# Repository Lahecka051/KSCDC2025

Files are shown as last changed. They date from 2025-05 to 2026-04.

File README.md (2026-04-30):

# KSCDC2025 — Team Prometheus

<p align="center">
  
  
  
  
  
  
  
</p>

> **스마트 드론을 활용한 실시간 화재 탐지 및 초기 소화 시스템**
>
> NVIDIA Jetson Orin Nano Super 기반, 딥러닝 객체인식을 통한 자율 순찰 및 소화볼 투하가 가능한 화재 대응 드론 시스템

---

## 목차

1. [프로젝트 개요](#프로젝트-개요)
2. [팀원](#팀원)
3. [시스템 아키텍처](#시스템-아키텍처)
4. [운용 시나리오](#운용-시나리오)
5. [폴더 구조](#폴더-구조)
6. [소프트웨어 모듈 상세](#소프트웨어-모듈-상세)
7. [하드웨어 사양](#하드웨어-사양)
8. [소프트웨어 스택](#소프트웨어-스택)
9. [통신 프로토콜](#통신-프로토콜)
10. [대회 일정](#대회-일정)
11. [라이선스](#라이선스)

---

## 프로젝트 개요

| 항목 | 내용 |
|---|---|
| 대회 | 2025 KSCDC (한국기계학회 창의설계경진대회) |
| 소속 | 경성대학교 |
| 기간 | 2025.05.02 ~ 2025.09.12 |
| 대회 홈페이지 | http://kscdc.ksme.or.kr/ |

## 팀원

| 이름 | 역할 |
|---|---|
| 이강민 | 조장 |
| 권혁준 | 팀원 |
| 송승진 | 팀원 |
| 유찬영 | 팀원 |
| 김철우 | 팀원 |

## 시스템 아키텍처

```
┌─────────────────┐       TCP/IP        ┌──────────────────┐       TCP/IP       ┌─────────────────┐
│   PC 관제 센터   │ ◄──────────────────► │   드론 (Jetson)   │                   │  Station (RPi)  │
│   (pc_server)   │    명령/보고 전송     │   (main.py)      │                   │  (station.py)   │
│                 │                      │                  │                   │                 │
│  - 지도 GUI     │  ← 화재 보고/이미지   │  - 화재 탐지      │                   │  - 소화볼 장전   │
│  - 경로 설정    │  → 순찰/진압 명령     │  - 자율 순찰      │                   │  - 도킹 정렬    │
│  - 진압 승인    │                      │  - 소화볼 투하    │                   │  - ToF 센서     │
│  - 사진 수신    │                      │  - 자동 착륙      │                   │                 │
└─────────────────┘                      └──────────────────┘                   └─────────────────┘
       :65524 (수신)                        :65523 (수신)                           :65525 (수신)
```

## 운용 시나리오

1. **순찰 명령** — PC 관제 센터에서 지도 위 경로점(Waypoint) 설정 후 드론에 전송
2. **자율 순찰** — 드론이 경로점을 따라 비행하며 정면 카메라(IMX477)로 YOLOv8s 화재/연기 탐지
3. **화재 확인** — 5초간 30프레임 이상 연속 감지 시 화재 확정, GPS 좌표 추정 후 화재 지점 이동
4. **하단 정렬** — 하단 카메라(IMX219)로 화재 위치에 드론 정밀 정렬
5. **화재 보고** — 현장 사진 촬영 후 PC 관제 센터로 좌표 및 이미지 전송
6. **홈 복귀 및 착륙** — 홈 좌표로 복귀 후, 빨간 마커 추적 기반 정밀 착륙
7. **진압 승인** — 관제 센터에서 화재 보고 확인 후 진압 승인 버튼 클릭
8. **소화볼 장전** — Station(Raspberry Pi)에 소화볼 장전 명령 전송
9. **소화볼 투하** — 드론이 화재 지점으로 재출격, 정렬 후 서보 모터로 소화볼 투하
10. **임무 완료** — 홈 복귀 및 착륙, 완료 상태 보고

## 폴더 구조

```
KSCDC2025/
├── README.md                          # 프로젝트 개요 (본 문서)
├── LICENSE                            # MIT License
├── .gitignore                         # Python/모델/로그 제외
├── .gitattributes                     # 줄바꿈 정규화 (LF)
│
├── Datasheets/                        # 부품 데이터시트 및 사양
│   ├── Filament.md                    #   3D 프린트 필라멘트
│   ├── Frame.md                       #   X6-X600 드론 프레임 (600mm)
│   ├── IMX219 Camera Module.md        #   하단 카메라 (160도 광각)
│   ├── IMX477 Camera Module.md        #   정면 카메라 (63도)
│   ├── JetsonOrinNanoSuper.md         #   NVIDIA Jetson Orin Nano Super
│   ├── MicoAir H743v2.md              #   FC (비행 컨트롤러)
│   ├── Motor & Propeller.md           #   Airgear 350 모터 & 프로펠러
│   └── Servo.md                       #   소화볼 투하용 서보 모터
│
├── Regular_Meeting/                   # 정기 회의록 (2025.05 ~ 2025.09)
│
├── Report/                            # 공식 보고서 (PDF)
│   ├── 설계제안서_프로메테우스_이강민.pdf
│   ├── 중간보고서_프로메테우스_이강민.pdf
│   └── 최종보고서_프로메테우스_이강민.pdf
│
├── STL/                               # 3D 프린트 모델 파일
│   ├── Drone/                         #   드론 탑재 부품 (소화볼 하우징/플레이트)
│   │   ├── Drone_4inch_Ball.stl
│   │   ├── Drone_BAT_House_Hook.stl
│   │   ├── Drone_BAT_House_Lower.stl
│   │   ├── Drone_BAT_House_Upper.stl
│   │   └── Drone_Bomb_Plate.stl
│   └── Station/                       #   스테이션 메커니즘 (랙앤피니언)
│       ├── Station_Bar.stl
│       ├── Station_Pinion.stl
│       └── Station_Rack.stl
│
└── Software/
    ├── Drone/                         # 드론 탑재 소프트웨어 (Jetson Orin Nano)
    │   ├── main.py                    #   메인 엔트리포인트 — 명령 수신 및 미션 분배
    │   ├── drone_controller.py        #   MAVLink FC 제어 (ARM, 이륙, GPS 이동, 착륙)
    │   ├── Fire_detector.py           #   YOLOv8s TensorRT 화재/연기 탐지 및 GPS 추정
    │   ├── Fire_extinguishing.py      #   소화볼 투하 미션 시퀀스
    │   ├── patrol.py                  #   자율 순찰 (경로점 이동 + 실시간 화재 감시)
    │   ├── Landing.py                 #   빨간 마커 추적 기반 정밀 착륙
    │   ├── DroneCommunicator.py       #   PC 관제 센터 TCP 통신 (보고/명령)
    │   ├── servo_control.py           #   소화볼 투하 서보 PWM 제어
    │   └── pipeline.py                #   GStreamer CSI 카메라 파이프라인
    │
    ├── PC/                            # PC 관제 센터 소프트웨어
    │   ├── pc_server.py               #   Tkinter 관제 GUI (지도, 경로, 화재 대응)
    │   ├── pc_rpi_server.py           #   Station(RPi) TCP 통신 서버
    │   └── pc_server.exe              #   빌드된 실행 파일
    │
    └── Station_WIP/                   # 드론 스테이션 [개발 중단 / Work In Progress]
        ├── station.py                 #   스테이션 메인 — 서보, ToF 센서, 도킹 제어
        ├── Doc_match.py               #   카메라 기반 도킹 마커 감지
        └── rpi_client.py              #   PC 서버 TCP 통신 클라이언트
```

## 소프트웨어 모듈 상세

### Drone (Jetson Orin Nano)

| 모듈 | 설명 |
|---|---|
| `main.py` | 시스템 진입점. PC로부터 TCP 명령을 수신하여 순찰(list) 또는 진압(EXTINGUISH) 미션을 스레드로 분배 |
| `drone_controller.py` | pymavlink 기반 FC 제어. GUIDED/RTL/LAND/BRAKE 모드 전환, ARM/DISARM, GPS 이동(goto_gps), 하버사인 거리 계산 |
| `Fire_detector.py` | YOLOv8s TensorRT 엔진으로 정면 카메라 화재/연기 탐지. 5초 30프레임 확정 로직, 카메라 각도 기반 화재 GPS 추정, 하단 카메라 객체 정렬 |
| `patrol.py` | 경로점 순회 + 실시간 화재 감시 스레드 병행. 화재 확정 시 화재 지점 이동 → 정렬 → 사진 촬영 → 홈 복귀 → 보고 전송 |
| `Fire_extinguishing.py` | 화재 지점 GPS 이동 → 하단 카메라 정렬 → 서보 180도 회전으로 소화볼 투하 → 홈 복귀 → 완료 보고 |
| `Landing.py` | 하단 카메라 빨간 마커(Red Dot) HSV 감지. 비례 제어로 마커 중앙 정렬하며 하강, 10초 미감지 시 LAND 모드 전환 |
| `DroneCommunicator.py` | PC 관제 센터로 화재 보고(좌표+이미지) 및 상태 업데이트 TCP 전송. 포트 65523에서 명령 수신 서버 운영 |
| `servo_control.py` | Jetson GPIO PWM 서보 제어. 0도=재장전(idle), 180도=투하 |
| `pipeline.py` | IMX477(30fps 1920x1080) / IMX219(21fps 1640x1232) 센서별 GStreamer 파이프라인 생성 |

### PC 관제 센터

| 모듈 | 설명 |
|---|---|
| `pc_server.py` | Tkinter + TkinterMapView 지도 GUI. 우클릭 경로점 추가, 순찰 명령 전송, 화재 보고 수신 시 지도 핑 + 사진 표시 + 진압 승인 |
| `pc_rpi_server.py` | Station(RPi)과의 TCP 서버. 소화볼 장전 명령 전송 및 응답 수신. 포트 65525 |

### Station [WIP — 개발 중단]

| 모듈 | 설명 |
|---|---|
| `station.py` | 서보 3축(전후/좌우/장전) + ToF 센서 4개(VL53L0X)로 드론 도킹 및 소화볼 장전 자동화 |
| `Doc_match.py` | CSI 카메라 빨간 마커 감지 (원형도/종횡비 필터링) 기반 도킹 정렬 |
| `rpi_client.py` | PC 서버 TCP 클라이언트. 명령 수신 큐 + JSON 응답 전송, 자동 재연결 |

## 하드웨어 사양

| 구성 요소 | 사양 |
|---|---|
| **개발보드** | NVIDIA Jetson Orin

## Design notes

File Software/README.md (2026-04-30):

# Software

KSCDC2025 프로메테우스 시스템 소프트웨어 구성. 3개 노드(PC 관제 / 드론 / 스테이션)로 구성된 분산 시스템.

```
PC 관제 (Tkinter GUI)  ───TCP───  Drone (Jetson Orin Nano)
        │
        └────TCP────  Station (Raspberry Pi, WIP)
```

## Drone/ — 드론 탑재 (Jetson Orin Nano Super)

YOLOv8s + TensorRT 기반 화재/연기 실시간 탐지 및 자율 비행/투하.

### 실행

```bash
cd Software/Drone
python3 main.py
```

### 의존성

- Python 3.10
- pymavlink, OpenCV (CUDA), TensorRT, ultralytics
- Jetson.GPIO
- GStreamer + nvarguscamerasrc (CSI 카메라)

### 진입점

`main.py` — PC 관제로부터 TCP 명령 수신 후 미션 분배 (순찰/진압).

## PC/ — 관제 센터 (Windows/Linux)

Tkinter + TkinterMapView 지도 GUI. 경로점 설정, 화재 보고 수신, 진압 승인.

### 실행

```bash
cd Software/PC
python pc_server.py
```

또는 빌드된 `pc_server.exe` 실행 (Windows).

### 의존성

- Python 3.10
- tkinter, tkintermapview, Pillow

## Station_WIP/ — 자동 장전 스테이션 [개발 중단]

Raspberry Pi 기반 자동 도킹/장전 시스템. 시간 부족으로 본 대회에서는 미투입, 향후 확장 작업용.

### 구성

- 서보 3축(전후 / 좌우 / 장전 회전)
- ToF 센서 4개 (VL53L0X) — 도킹 거리 측정
- CSI 카메라 — 빨간 마커 도킹 정렬

## 통신 포트

| 노드 | 수신 포트 | 용도 |
|---|---|---|
| 드론 | 65523 | PC → 드론 명령 |
| PC | 65524 | 드론 → PC 보고 |
| Station | 65525 | PC → Station 장전 명령 |

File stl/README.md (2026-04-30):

# STL — 3D Print Models

KSCDC2025 프로젝트에서 자체 설계 후 3D 프린팅한 부품 모델 모음.

## Drone/

드론 본체에 장착되는 부품. 소화볼(4인치)을 거치/투하하기 위한 BAT(Bomb Attachment) 하우징과 플레이트.

| 파일 | 용도 |
|---|---|
| `Drone_4inch_Ball.stl` | 4인치 소화볼 검증용 더미 모델 |
| `Drone_BAT_House_Upper.stl` | 소화볼 하우징 상부 |
| `Drone_BAT_House_Lower.stl` | 소화볼 하우징 하부 |
| `Drone_BAT_House_Hook.stl` | 소화볼 고정 후크 (서보 회전으로 해제) |
| `Drone_Bomb_Plate.stl` | 드론 하단 BAT 마운트 플레이트 |

## Station/

스테이션(자동 장전기)의 랙앤피니언 메커니즘 부품. 개발 중단(WIP) 상태.

| 파일 | 용도 |
|---|---|
| `Station_Rack.stl` | 직선 이송용 랙 기어 |
| `Station_Pinion.stl` | 서보 결합 피니언 기어 |
| `Station_Bar.stl` | 가이드 바 |

## 출력 권장 사양

| 항목 | 값 |
|---|-----|
| 필라멘트 | PLA (자세한 사양은 [Datasheets/Filament.md](../Datasheets/Filament.md)) |
| 레이어 두께 | 0.2 mm |
| 인필 | 30 ~ 50% (하중 부품은 50%) |
| 서포트 | 부품별 필요 시 |

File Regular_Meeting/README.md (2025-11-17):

# == 정기 회의록 ==
- KSCDC2025 팀 프로젝트 회의 진행중 나온 의견을 정리하는 장소입니다.
- 메인 페이지의 정리된 회의 내용은 회의 종료 후 2일 이내 업데이트 됩니다.
- 자세한 사항은 당일 회의록을 참고하시기 바랍니다.

# Paste_Data : 09.11(목) (latest update) 

### 정기 회의일
- 매주 (수,목)요일 14:00 ~ 20:00

## 논의 내용
- 하드웨어 & 소프트웨어 제작

## 진행 상황
### 소프트웨어
- 젯슨 CSI 카메라 객체인식 테스트 YOLOv8s
- FC의 데이터를 텔레메트리를 이용하여 실시간 모니터링 가능한 지상국 구축
- FC의 모터 PWM 신호 애널라이징 후 신호 복제하여 무선 모터 조종 테스트

### 기계공학적인 차별점이 필요
- 드론 하단부 소화탄 발사기 ( 소화탄 다연장 회전식 매커니즘 ) 탈부착
- 탈착일때 정찰용, 부착일때 화재진압용
- 드론스테이션 자동화 플랫폼

## 확정된 부품
- 예산 : 30만원 + @

#### 모터 : 이동희 교수님 
- Airgear 350 Combo Set Multi-Rotor UAV Power 4pcs Set X2
- 9.5 X 4.5 two blade Propeller
  
#### FC(Flight Controller)
- 미코에어 H743 V2 신형 픽스호크 비행 컨트롤러 (ARDUPILOT ONLY)
- [FC 구매 링크](https://ko.aliexpress.com/item/1005008824819033.html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)

#### 카메라
- 정면 : IMX477 6mm 63 degree
- 바닥 : IMX219 160 degree

#### 배터리 
- LiPo 4S(14.8V) 8,400mAh 130C X2 
- IMAX B6 LiPo 충전기
- [배터리 구매 링크](https://ko.aliexpress.com/item/1005001956377380.html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)
- [충전기 구매 링크](https://ko.aliexpress.com/item/1005005231331856.html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)

#### 개발보드 
- Jetson Orin Nano Super
- [개발보드 공식 링크](https://www.nvidia.com/ko-kr/autonomous-machines/embedded-systems/jetson-orin/nano-super-developer-kit/)

### 소프트웨어
- UBUNTU_GUI 22.04 LTS (Jetpack6.2.1)
- Ardupilot 5.4.2
- USED OPENCV CUDA TensorRT
- YOLO MODEL : YOLOv8s

## 프레임
- 페이로드 : 3kg 이하, 사이즈 : 300x300 mm 이상
- X6-X600 FPV 프레임 600mm / 30A ~ 40A / 2212 920KV 모터
- [프레임 구매 링크](https://ko.aliexpress.com/item/1005008274592701.html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)

### 부품 공식 제원 상 무게
- jetson orin nano super : Dimensions = 100mm x 79mm x 21mm, Weight = 176g, Power = 5V_Input(5W ~ 25W)
- Camera : 수정
- Flight Controller Spec : Mounting = 30.5mm x 30.5mm x 4mm, Dimensions = 36mm x 36mm x 8mm, Weight = 10g
- 14.8V 8400mah 130C 리포 하드케이스 크기: 138 x 47 x 49mm 무게 639g.
- 소화볼 규격: 지름 4inch(약 100mm), 약 400g
- [소화볼 규격 링크](https://fireds.com/product/%EC%BD%94%EB%81%BC%EB%A6%AC%EC%86%8C%EB%B0%A9%EB%A7%88%ED%8A%B8-%ED%99%94%EC%9D%B4%EC%96%B4%EB%B3%BC4%EC%9D%B8%EC%B9%98-%ED%99%94%EC%9E%AC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)
## 앞으로 진행할 내용
- 젯슨 객체인식 소프트웨어 & 지상국 소프트웨어 구체화

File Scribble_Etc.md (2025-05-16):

## Jetson Orin Nano Super (66만원) 
- AI Performance	67 INT8 TOPS
- GPU	NVIDIA Ampere architecture with 1024 CUDA cores and 32 tensor cores
- CPU	6-core Arm® Cortex®-A78AE v8.2 64-bit CPU 1.5MB L2 + 4MB L3
- Memory 8GB 128-bit LPDDR5 102 GB/s
- Storage	Supports SD card slot and external NVMe
- Power	7W – 25W

### YOLO v8 Processing data = Y1

▲

## [ UART Protocol Communication ]
- ### 통신에 영향을 주는 요소
- 클럭에 따른 BaudRate 에러율 ( 목표 : 0% ) 
- Serial Communication Module Maximum data Throughput
- 통신에 영향을 주는 BaudRate에 따른 Cable Length ( Option : 차폐 기능 )
- 해상도에 따른 처리 시간 변화 ( BaudRate와 Cable Length에 영향을 받음 )

▼

## FC ( Flight Controller )

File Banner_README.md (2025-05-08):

# KSCDC2025 [Team Prometheus]
KSCDC2025 Kyungsung Univ Project

# 2025.05.02 ~ 2025.09.12
- 설계제안서 접수: 2025년 4월 7일(월) ~ 5월 2일(금) 온라인 접수
- 중간보고서 접수: 2025년 6월 2일(월) ~ 6월 27일(금) 온라인 접수
- 본선 진출 팀 선정결과: 2025년 7월 14일(월) email 통보
- 최종보고서 접수: 2025년 8월 25일(월) ~ 9월 12일(금) 온라인 접수
- 최종 본선 진출 팀 선정결과: 2025년 9월 29일(월) email 통보
- 최종 본선 진출 팀 구두발표, 심사 및 시상 : 2025년 10월 25일(토)

# 스마트 드론을 활용한 실시간 화재 탐지 및 초기 소화 시스템
Nvidia Jetson Development Board 기반 소화탄 투척이 가능한 딥러닝 자율주행 드론

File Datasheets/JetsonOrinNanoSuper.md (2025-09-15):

# Jetson Orin Nano Super Specifications



# GPIO PINS MAP (33_PWM Activated)



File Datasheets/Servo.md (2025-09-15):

# Datasheet 
Used Servo : [SG90](http://www.ee.ic.ac.uk/pcheung/teaching/DE1_EE/stores/sg90_datasheet.pdf)



# Trigger Image


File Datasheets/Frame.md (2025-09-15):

# X600 Quardcopter Frame Specifications
[구매링크](https://speedyfpv.com/products/600mm-carbon-fiber-hexacopter-drone-frame-kit-new)

Frame Head Diameter ----> 



# 3K Carbon Fiber Properties
PDF Link ----> [3K Carbonfiber](https://www.toraycma.com/wp-content/uploads/T300-Technical-Data-Sheet-1.pdf)



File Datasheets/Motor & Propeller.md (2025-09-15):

# T-Moter 2213/920KV 모터 세트
[구매링크](https://store.tmotor.com/product/air-gear-350-combo-set.html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)

# Motor Diameter


# Power Efficiency


# Propeller Specifications


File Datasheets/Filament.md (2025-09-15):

# 필라멘트 (PLA, ABS)

### 드론 상단부 (열영향 비교적 적게 받는 부분 설계에 사용)

구매링크 : [PLA](https://smartstore.naver.com/3d-rainbow/products/8816025124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)

===================================================================================

### 드론 하단부 (열영향 비교적 많이 받는 부분 설계에 사용)

구매링크 : [ABS](https://smartstore.naver.com/sondori/products/9590869360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)

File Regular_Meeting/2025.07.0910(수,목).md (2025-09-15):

# 7주차 회의내용

## 논의 내용
- 하드웨어 & 소프트웨어 제작

## 진행 상황
### 소프트웨어
- YOLOv8s의 화재 탐지모델 데이터셋 구글 코랩을 이용하여 학습
- FC의 데이터를 텔레메트리를 이용하여 실시간 모니터링 가능한 환경 구축
- FC의 accypr & gps data를 이용한 드론 방향제어 로직 생성

### 부품 공식 제원 상 무게
jetson orin nano super : Dimensions = 100mm x 79mm x 21mm, Weight = 176g, Power = 5V_Input(5W ~ 25W)
Camera : 3g x 2 = 6g
Flight Controller Spec : Mounting = 30.5mm x 30.5mm x 4mm, Dimensions = 36mm x 36mm x 8mm, Weight = 10g

# 0710 할 일
1. 필라멘트 도착하면 그리퍼 출력 -> 소화볼 출력
2. 역설계 모델링
3. 피드백 고려

# 1. 소화볼 규격
4인치 / 약 10cm // 6인치 고려 / 약 15cm

[소화볼 판매 사이트](https://fireds.com/product/%EC%BD%94%EB%81%BC%EB%A6%AC%EC%86%8C%EB%B0%A9%EB%A7%88%ED%8A%B8-%ED%99%94%EC%9D%B4%EC%96%B4%EB%B3%BC4%EC%9D%B8%EC%B9%98-%ED%99%94%EC%9E%AC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)

# 2. 필라멘트 (PLA, ABS)
[PLA](https://smartstore.naver.com/3d-rainbow/products/8816025124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)

[ABS](https://smartstore.naver.com/sondori/products/9590869360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)

# 3. 기판 / 배터리 / Jetson / 배치 고려
-> 아래쪽 V자 평판 구조 새로 제작



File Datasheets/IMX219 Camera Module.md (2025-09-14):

# IMX219 160도 광각 카메라 모듈 8MP

## 사양
- 인터페이스 : CSI
- 해상도 : 3280 × 2464
- 크기 : 25mm × 24mm
- 케이블 길이 : 약 16cm
- 4개의 나사 구멍으로 3.3V의 직류 공급이 가능합니다.

## 렌즈 사양
- CMOS 크기 : 1/4인치
- 조리개 : F2.35
- 초점 거리 : 3.15mm
- 화각 : 160°
- 왜곡 : <14.3%

## 구성품
- 카메라모듈 1개
- 15핀 FFC 케이블 1개
 
## 카메라 테스트 명령어
DISPLAY=:0.0 gst-launch-1.0 nvarguscamerasrc ! 'video/x-raw(memory:NVMM), width=3280, height=2464, format=(string)NV12, framerate=(fraction)20/1' ! nvoverlaysink -e

## 화상이 빨갛게(자주빛으로) 보일 때
- wget https://www.waveshare.com/w/upload/e/eb/Camera_overrides.tar.gz
- tar zxvf Camera_overrides.tar.gz
- sudo cp camera_overrides.isp /var/nvidia/nvcam/settings/
- sudo chmod 664 /var/nvidia/nvcam/settings/camera_overrides.isp
- sudo chown root:root /var/nvidia/nvcam/settings/camera_overrides.isp

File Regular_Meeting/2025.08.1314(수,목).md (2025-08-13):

# 진행상황
## 소프트웨어

착륙 객체인식 CSI 카메라 1개 정확도
FHD 기준 지름 5CM 착륙 H 마커 인식거리 1.5M

화재 객체인식 CSI 카메라 2개 작동 성공 & 객체인식 정확도 상세 제원 필요
70~80cm 거리 지름 5CM 화재이미지 인식

드론 UART MAVLink2 연결 성공
Jetson PIN6(GND)==FC(UART4(black)), PIN8(TX)==FC(UART4(green)), PIN10(RX)==FC(UART4(yellow)) 연결
드론 데이터 통신 & 방향제어 로직 제작중

관제센터 GUI 제작중

## 하드웨어
  
배터리 하우징 완성
FC& 전력분배PCB 하우징 완성
카메라 하우징 완성
젯슨 하우징 환성
소화탄 투하기 제작중

# 앞으로 할일

## 소프트웨어

드론스테이션 통신 구상하기

## 하드웨어
소화탄 투하기 만들기
드론스테이션 구상하기

### 마감 08월 29일 까지

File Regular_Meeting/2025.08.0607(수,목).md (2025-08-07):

# 진행상황
## 소프트웨어

착륙 객체인식 CSI 카메라 1개 정확도
FHD 기준 지름 5CM 착륙 H 마커 인식거리 1.5M

화재 객체인식 CSI 카메라 2개 작동 성공 & 객체인식 정확도 상세 제원 필요

드론 UART MAVLink2 연결 성공
Jetson PIN6(GND)==FC(UART4(black)), PIN8(TX)==FC(UART4(green)), PIN10(RX)==FC(UART4(yellow)) 연결

## 하드웨어
  
배터리 하우징 완성
FC& 전력분배PCB 하우징 완성
카메라 하우징 제작중

# 앞으로 할일

## 소프트웨어

드론스테이션 통신 구상하기
관제센터 GUI 만들기

## 하드웨어

Jetson 적층 하우징 만들기
소화탄 투하기 만들기
드론스테이션 구상하기

### 마감 08월 29일 까지

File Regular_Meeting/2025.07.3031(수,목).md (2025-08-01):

하드웨어팀 소화볼 투하기 & 배터리 하우징 모델링 & 젯슨, FC 고정 하우징 제작

소프트웨어팀 FC 젯슨 UART 의존성 업데이트 & 지상국에서 모터 제어 PWM 신호 측정 및 싱크로나이즈 작업 1명, 젯슨 OPENCV CUDA 관련 의존성 업데이트 및 CSI 카메라 객체인식 테스트 2명

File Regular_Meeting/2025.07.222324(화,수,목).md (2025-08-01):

하드웨어팀 소화볼 투하기 & 배터리 하우징 모델링

소프트웨어팀 FC 젯슨 UART 의존성 업데이트 & 지상국에서 모터 제어 PWM 신호 측정 및 싱크로나이즈 작업 1명, 젯슨 OPENCV CUDA 관련 의존성 업데이트 및 CSI 카메라 테스트 2명

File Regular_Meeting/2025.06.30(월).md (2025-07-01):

# 6주차 회의내용

## 논의 내용
- 하드웨어 제작 정기 회의 날짜 지정
- 하드웨어 & 소프트웨어 각자 맡은 작업 구체화

## 확정된 부품

#### 모터 : 이동희 교수님 
- Airgear 350 Combo Set Multi-Rotor UAV Power 4pcs Set X2
- 9.5 X 4.5 two blade Propeller
  
#### FC(Flight Controller)
-미코에어 H743 V2 신형 픽스호크 비행 컨트롤러

#### 카메라
- 정면 : IMX219 160 degree
- 바닥 : IMX219 120 degree

### 배터리 
- LiPo 4S(14.8V) 8,400mAh 130C X2 
- IMAX B6 LiPo 충전기

### 개발보드 :  Jetson Orin Nano Super

### 소프트웨어
- Linux_Based (Ardupilot, YOLOv8s, UBUNTU_GUI 24.2)

## 프레임
- X6-X600 FPV 프레임 600mm / 30A ~ 40A / 2212 920KV

### 부품 공식 제원 상 무게
jetson orin nano super : Dimensions = 100mm x 79mm x 21mm, Weight = 176g, Power = 5V_Input(5W ~ 25W)
Camera : 3g x 2 = 6g
Flight Controller Spec : Mounting = 30.5mm x 30.5mm x 4mm, Dimensions = 36mm x 36mm x 8mm, Weight = 10g

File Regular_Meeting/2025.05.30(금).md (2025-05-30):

# 4주차 회의내용

## 논의 내용
- 모터 추가에 대한 쿼드콥터에서 헥사콥터로 형태 변경
- 부품 결정 및 구매
- 대한기계학회에서 제시한 보완 사항 논의

## 확정된 부품

### 모터 : 이동희 교수님 
- Airgear 350 Combo Set Multi-Rotor UAV Power 4pcs Set X2

### FC(Flight Controller)
-미코에어 H743 V2 신형 픽스호크 비행 컨트롤러

### 카메라
- 정면 : IMX219 160 degree
- 바닥 : IMX219 120 degree

## 배터리 : 4S(14.8V) 
- 5,000mAh ~ 10,000mAh

### 개발보드 :  Jetson Orin Nano Super

### 소프트웨어
- Linux_Based (Ardupilot, YOLOv8s, UBUNTU_GUI 24.2)

## 프레임
- 우선사항 [ 프레임 무게, 페이로드 : 3kg 까지 ]
- 페이로드 : 3kg 이하, 사이즈 : 300x300 mm 이상

## 추가할 사항
- 기성품 소화탄 규격에 맞춰 설계할 필요있음

## 확정된 사항
-

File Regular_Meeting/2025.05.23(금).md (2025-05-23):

# 3주차 회의내용

## 논의 내용
- 부품 구매리스트 확정 및 중가보고서에 작성할 개념 설계적인 부분 보완

### 기계공학적인 차별점이 필요
- 드론 하단부 소화탄 발사기 ( 소화탄 다연장 회전식 매커니즘 ) 탈부착 가능하게
- 탈착일때 정찰용, 부착일때 화재진압용
- 드론스테이션 자동화 플랫폼 ( 고려 )

## 확정된 부품

### 모터 : 이동희 교수님 공짜
- Airgear 350 Combo Set Multi-Rotor UAV Power

### FC(Flight Controller) 100,000원
-미코에어 H743 V2 신형 픽스호크 비행 컨트롤러

### 카메라
- 정면 : IMX219 160 degree 18,000원
- 바닥 : IMX219 120 degree 15,000원
- Total : 35,000원
  
## 미확정 부품

## 배터리 : 4S(14.8V) 
- 5,000mAh ~ 10,000mAh 70,000원

### 개발보드 : 박장식 교수님 (Jetson Board)
- 개발보드 : 박장식 교수님한테 대여

### 소프트웨어
- Linux_Based (Ardupilot, YOLO(Version not yet), UBUNTU 18 OR 20

## 프레임
- 우선사항 [ 프레임 무게, 페이로드 : 3kg 까지 ]
- 페이로드 : 2kg 이하, 사이즈 : 300x300 mm 이상

## 추가할 사항
- 기성품 소화탄 규격에 맞춰 설계할 필요있음
- 각 부품별로 무게 취합 (최대 2kg)

## 확정된 사항
- 
## 앞으로 진행 계획

**팀원 김형찬 미참**

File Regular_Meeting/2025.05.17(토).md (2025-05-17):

# 2주차 회의내용 (수요일과 동일)

## 논의 내용
- 예산 확정에 따른 구체적인 계획수립 및 중간보고서 작성 방향성 제시

### 기계공학적인 차별점이 필요
- 드론 하단부 소환탄 발사기 ( 소화탄 다연장 회전식 매커니즘 ) 탈부착 가능하게
- 탈착일때 정찰용, 부착일때 화재진압용
- 드론스테이션 자동화 플랫폼 ( 고려 )

## 필요한 부품 선정 ( 1~3개 )
### 프레임(쿼드콥터)
- 우선순위 : 크기, 하중무게 , 비용
- 크기 : 최소 300mm X 300mm (min)
- 하중무게 : 2kg ~ 5kg (min ~ max)
- 예산 : 최대 5만원

### 모터 : 이동희 교수님 (Unknown) 
- 우선순위 : 토크, RPM, 무게, 비용
- 토크 :
- RPM :
- 무게 :
- 예산 : 최대 20만원

### 개발보드 : 박장식 교수님 (Jetson Board)
- 개발보드 : 박장식 교수님한테 대여
- 정확한 기종은 확정 안됨 & 보드 호환 카메라 모듈 유무 확인 후 대여 가능한지 물어보기
  
### 소프트웨어
- Linux_Based (Ardupilot, YOLO(Version not yet)

### FC(flight controller) 
- 예산 : 최대 15만원

### FC_List
- 마텍 f722-se 드론 컨트롤러
- 픽스호크 시리즈 별로 알아보기
  
## 추가할 사항
### 3주차 금요일 까지 과제
- 구글독 스페이스에 각자 담당한 부품 선정 리스트 만들어 오기

## 확정된 사항
- 지원 예산 : 30만원 (일시지급, 사용 후 정산) / 필수기재 사항 : [ 제품명 & 금액 ]
- 추가 예산 : 고려중 (인당 n만원)
- 
## 앞으로 진행 계획
- 3주차 : 부품 구매 확정된 내용 바탕으로 중간보고서 작성에 필요한 이론적인 내용 및 실제 작성

**팀원 김형찬 미참**

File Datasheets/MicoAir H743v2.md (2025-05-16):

# MicoAir743 V2 비행 컨트롤러
- Ardupilot/PX4/INAV/Betaflight 를 지원하는 듀얼 IMU 및 나침반 센서가 내장된 고성능 H743 비행 컨트롤러 입니다. 
- 펌웨어/ 핀아웃 링크: https://micoair.com/flightcontroller_micoair743v2/
- 매뉴얼: https://micoair.com/docs/micoair743-user- manual/
- 기본적으로 Ardupilot 이 설치되어 있습니다. 
- *PX4 설치시 stm32cube Programmer 를 이용하여 bootloader (bin 또는 ef) 파일을 먼저 설치하시고, QGC 에서 px4 펌웨어를 설치하시면 됩니다. 
- *펌웨어 설치 방법 참고 : https://youtu.be/H7TsouQIBfg 
- ESC 가 8비트 Bluejay 에서 32비트 AM32 로 업그레이드 되었습니다.
- 납땜 전에 반드시 USB 를 먼저 꽂아서 정상 작동하는지 점검하십시오. 납땜 이후에는 어떤 경우에도 초기 불량 처리가 되지 않습니다.

## Ardupilot 셋팅시 참고 파라미터 > 
- SERVO1_FUNCTION : 34 (M2) 
- SERVO2_FUNCTION : 35 (M3) 
- SERVO3_FUNCTION : 36 (M4) 
- SERVO4_FUNCTION : 33 (M1) 
- MOT PWM -TYPE : 6( (Dshot 600)
- SERVO _DSHOT ESC : 3 (AM32) 
- SERVO_BLH_BDMASK : 15 (생략가능, 적용시 RPM체크 가능) SERVO_BLH_AUTO : 1 
- NTF_BUZZ_TYPES : 3 (생략 가능, 적용시 모터를 부저로 사용)

## 상세 제원 
- MCU : STM32H743VIH6, 480MHz, 2MB 플래시 
- IMU : BMI088/BMI270 
- 바로 : SPLO6 
- 나침반 : QMC5883L 
- OSD : AT7456E 
- MicroSD 카드 슬롯 
- 8 x UART 
- 11 x PWM 
- 1 x 12C 
- 1 x SWD 
- 2 x ADC(VBAT, 전류) 
- USB 타입-C
- DJI 03/04 VTX 커넥터
- BEC 5V 3A 출력(컨트롤러, 수신기, GPS, 광학 흐름 또는 기타 장치용) 
- BEC 12V 3A 출력(비디오 송신기, 카메라용) 
- Bluetooth 원격 측정(UART8에 내부적으로 연결됨, 통신 속도 115200)
- VBAT 입력 범위: 2-6S(6-27V)

## UART 매핑( Ardupilot )
- 직렬0 -> USB 
- SERIAL1 -> UART1 (MAVLink2,DMA 지원) 
- SERIAL2 -> UART2(DisplayPort,DMA 지원) 
- SERIAL3 -> UART3(GPS, DMA 지원) 
- SERIAL4 -> UART4(MAVLink2, DMA 지원) 
- SERIAL5 -> UART5(DMA 지원) 
- SERIAL6 -> UART6( RCIN,DMA-활성화됨) 
- SERIAL7-> UART7(ESC 원격 측정, DMA 지원) 
- SERIAL8 -> UART8(DMA 활성화됨, 온보드 Bluetooth Telemetry에 연결됨 )

## UART 매핑(PX4)
- ttyACMo -> USB 
- ttyS0 -> TEL1 -> UART1 
- ttyS1 -> GPS2 -> UART2 
- ttyS2 -> GPS1 -> UART3 
- ttyS3 -> TEL2 -> UART4 
- ttyS4 -> TEL3-> UART5 
- ttyS5 -> RC -> UART6 
- ttyS6 -> UART6 -> UART7 
- tyS7 -> TEL4/SERIAL4 -> UART8

## RC 입력( Ardupilot )
- UART6는 ArduPilot이 지원하는 모든 수신기 프로토콜과 호환됩니다. 
- PPM은 지원되지 않습니다. 
- SBUS/DSM/SRXL은 RX6 핀에 연결됩니다. 
- FPort는 TX6에 대한 연결이 필요합니다. 
- FPort 수신기를 참조하세요. 
- CRSF는 RX6뿐만 아니라 TX6 연결도 필요하며 자동으로 원격 촉정을 제공합니다. 
- SRXL2는 TX6에 연결해야 하며 자동으로 원격 측정을 제공합니다. SERIAL6_OPTIONS를 "4"로 설정합니다.
- 모든 UART는 ArduPilot의 RC 시스템 연결에도 사용할 수 있으며 PPM을 제외한 모든 프로토콜과 호환됩니다. 자세한 내용은 무선 제어 시스템을 참조하세요.

## OSD 지원(Ardupilot) 
- MicoAir743 V2는 0SD_TYPE 1(MAX7456 드라이버 )를 사용하여 온보드 0SD를 지원합니다.
- 동시에 DisplayPort OSD는 HD VTX 커넥터에서 사용할 수 있습니다.

## VTX 지원 
- SH1.0-6P 커넥터는 DJI 에어 유닛/HD VTX 연결을 지원합니다.
- 프로토콜의 기본값은 DisplayPort 입니다.
- 커넥터의 핀 1은 12V이므로 5V가 필요한 주변 장치에 연결하지 않도록 주의하십시오.

## PWM 출력 
- MicoAir743 V2은 최대 11개의 PWM 출력을 지원합니다. 
- 채널 1-8은 DShot 및 양방향 DShot을 지원합니다. (현재 PX4&INAV는 BDShot 기능을 지원하지 않습니다) 
- PWM 출력 공유는 그룹화되어 있으며 모든 그룹은 동일한 출력 프로토콜을 사용해야 합니다. 
- 1,2,3,4는 그룹 1입니다.
- 5,6은 그룹 2입니다.
- 7,8,11은 그룹 3입니다.
- 9.10은 그룹 4입니다. 
-  참고 : PWM11은 "LED" 핀입니다. 이것이 직렬 LED 사용으로 구성된 경우 PWM7, 8은 직렬 LED로만 사용할 수 있습니다.

## 배터리 모니터링 
- 보드에는 내부 전압 센서가 있고 ESC 커넥터에는 외부 전류 센서 입력을 위한 연결 장치가 있습니다. 
- 전압 센서는 최대 6S LiPo 배터리를 처리할 수 있습니다. 
- Ardupilot의 기본 배터리 매개변수는 다음과 같습니다. 
- BATT_VOLT_PIN 10  
- BATT_CURR_PIN 11
- BATT_VOLT-MULT 21.2
- BAATT_CURR_SCALE 40.2

## 나침반 
- MicoAir743 V2에는 나침반 센서(QMc5883L)가 내장되어 있으며 SDA 및 SCL 커넥터에서 12C를 사용하여 외부 나침반을 연결할 수도 있습니다.

## 규격 
- 장착: 30.5 x 30.5mm, $4mm 
- 크기: 36 36 x 8mm 
- 무게: 10g





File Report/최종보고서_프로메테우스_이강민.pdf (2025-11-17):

- 1 -

# 대한기계학회 주최

# 제15회 전국학생설계경진대회(2025년)

# 설계 최종 보고서

참가부 | 대학부 ( O )
참가분야 | 공모주제 ( O ) / 자유주제 ( )
참가팀명 | 프로메테우스
설계제목 | 스마트 드론을 활용한 실시간 화재 탐지 및 초기 소화 시스템
지도교수/교사 | (소속) 경성대학교 (성명) 박장식 (연락처) 010-5503-6198 (이메일) jsipark@ks.ac.kr
대표자 (신청인) | 성명 | 소속 | 연락처 (휴대폰) | E-mail | 주소
| 이강민 | 경성대학교 전자공학과 | 010-4928-2105 | gtbbknq2001@kyu ngsung.ac.kr | 부산광역시 수영구 황령대로431

# 참가팀원 인적사항

NO | 성명 | 소속 / 학년 | E-MAIL
1 | 이강민 | 경성대학교 전자공학과 / 4학년 | gtbbonq2001@kyungsung.ac.kr
2 | 송승진 | 경성대학교 전자공학과 / 4학년 | 해당사항 없음
3 | 권혁준 | 경성대학교 전자공학과 / 4학년 | 해당사항 없음
4 | 유찬영 | 경성대학교 메카트로닉스공학과 / 4학년 | cksdud0515@naver.com
5 | 김철우 | 경성대학교 메카트로닉스공학과 / 4학년 | 해당사항 없음
- 2 -

# 설계 요약문

참가분야 | 공모주제 ( O ) / 자유주제 ( )
참가팀명 | 프로메테우스
설계제목 | 스마트 드론을 활용한 실시간 화재 탐지 및 초기 소화 시스템
대표자명 | 이강민

요약문

최근 산불 발생 빈도와 피해 규모가 급증함에 따라 초기 대응 체계의 혁신이 시급한 과제로 대두되고 있다. 본 연구는 산림청과 소방청으로 이원화된 지휘체 계와 24시간 상시 관제 인프라 부재로 인한 대응 지연 문제를 해결하기 위해, 기 존의 상용 기술들을 통합하여 자율 화재 진압 드론 시스템을 구현하였다. 시스템 구현을 위해 상용 T-Motor 모터와 600mm 헥사콥터 프레임을 활용한

3kg 비행 플랫폼을 구성하고, NVIDIA Jetson Orin Nano Super에 YOLOv8s 모델을 TensorRT로 최적화하여 탑재함으로써 640×640 해상도에서 45+ FPS의 실시간 화 재 감지(mAP 87.3%)를 구현하였다. 상용 센서들(IMU, 기압계, GPS)과 오픈소스 EKF 알고리즘을 조합한 센서 융합 시스템과 적응형 PID 제어를 통해 5.4m/s 열 기류 환경에서도 위치 정확도는 ±0.3m을 유지하였다. 삼각측량 기반 GPS 좌표 변환 알고리즘으로 ±2.9m의 화재 위치 추정 정확도

를 확보하였으며, 3D 프린팅으로 제작한 볼캡 방식 투하기를 통해 4인치 소화볼 2개의 순차 투하를 구현하였다. MAVLink2 프로토콜과 오픈소스 라이브러리를 활용한 시스템 통합 결과, 화재 감지부터 소화볼 투하까지 평균 4분 32초가 소요 되었다. 시제품 시험은 실제 산악 화재 환경 검증과 옵티컬 라이다 센서을 적용하지

못하였다. 본 작품은 객체탐지 딥러닝 모델과 개방형 소프트웨어(Open-source software)의 효과적인 통합을 통해 저비용 자율 화재 대응 시스템의 실현 가능성 을 입증하였으며, 모듈화 설계로 기존 드론 플랫폼과 높은 호환성을 확보하여 실 용화 가능성을 제시하였다. 설계프로젝트의

입상 이력

☑ 본 설계보고서가 최종 입상할 경우 대한기계학회 논문집C권에 투고됨을 동의함 ※ 투고된 논문의 심사 및 출판은 본 경진대회 심사와는 별개로 진행됨. ※ 설계 요약문은 공개될 예정이며, 제출 시 이에 동의하는 것으로 간주함. ※ 제공된 개인정보는 심사과정에만 사용되며, 제출 시 이에 동의하는 것으로 간주함.

- 3 -

## 스마트 드론을 활용한 실시간 화재 탐지 및 초기 소화 시스템

### 이강민* · 송승진* · 권혁준* · 유찬영* · 김철우 · 박장식*†

*경성대학교 전자공학과·**경성대학교 메카트로닉스공학과

### Smart Drone-based System for Real-Time Fire Detection and Early Extinguishing

Kangmin Lee*

, Seungjin Song*

, Hyeokjun Gwon*

, Chanyung Lyu* Cheolwoo Kim* and Jangsik Park*†

* Dept. of Electronic Enginerring, Kyungsung Natational University
** Dept. of Mechatronics, Kyungsung Natational University

(Received September 13, 2025 ; Revised September 13, 2025 ; Accepted September 13, 2025)

Key Words: Reverse Engineering(역설계), Distribution Focal Loss(분포 초점 손실), EKF(확장 칼만 필터), Triangulation(삼각측량기법)

초록: 본 연구는 산불 초기 신속한 대응을 위해 객체탐지 딥러닝과 추적 알고리즘을 적용한 자율 화재 진압 드론을 개발 구현하였다. T-Motor 기반 헥사콥터에 Jetson Orin Nano Super와 YOLOv8s 모델을 탑 재하여 실시간 화재 감지(87.3% mAP@0.5, 45+ FPS)를 구현하고, EKF 센서 융합과 적응형 PID 제어로 5.4m/s 열기류에서도 ±0.3m 위치 정확도를 달성하였다. 삼각측량 기반 GPS 추정(오차 ±2.9m)과 3D 프린 팅 소화볼 투하기를 통해 화재 감지부터 투하까지 4분 32초의 신속 대응을 실현하였다. 본 연구는 오픈 소스 기반 모듈화 설계로 기존 드론과의 호환성을 확보하여 저비용 자율 화재 대응 시스템의 실용화 가능성을 입증하였다.

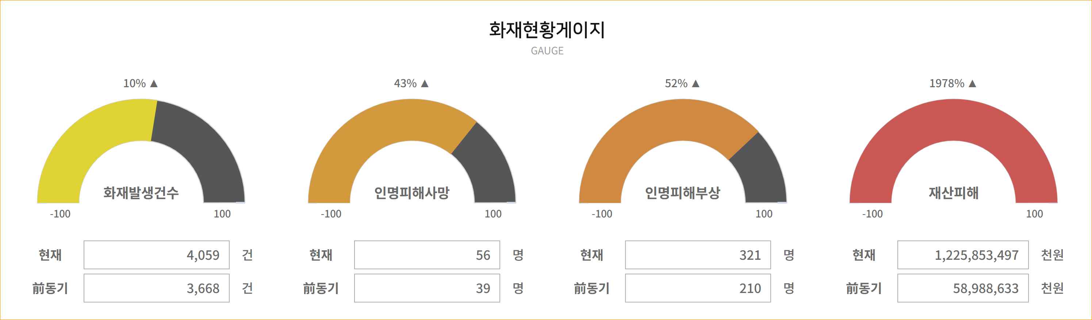
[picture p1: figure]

Abstract: This study implemented an autonomous fire suppression drone prototype by integrating commercial technologies to address wildfire initial response delays. The system combines a T-Motor hexacopter platform with Jetson Orin Nano Super and YOLOv8s model, achieving real-time fire detection (87.3% mAP@0.5, 45+ FPS). EKF sensor fusion and adaptive PID control maintained ±0.3m position accuracy in 5.4m/s thermal updrafts. Triangulation-based GPS estimation (±2.9m error) and 3D-printed fire extinguishing ball dropper enabled 4-minute 32-second response time from detection to deployment. The modular open-source design ensures compatibility with existing drone platforms, demonstrating feasibility of low-cost autonomous fire

response systems.

†Corresponding Author, jsipark@ks.ac.kr
Ⓒ 2025 The Korean Society of Mechanical Engineers | - 4 -
1. 서 론

최근 기후변화로 인하여 산불 발생이 많아지고, 대형화하는 추세이다. 2025년 3월 대한민국에서 연속 적으로 발생한 산불은 역사상 최악의 재난으로 기록되었다. 경남 산청을 시작으로 전국 11곳에서 동시 다발적으로 발생한 산불의 피해 상황을 Fig. 1에 나타내었다. 총 48,238ha의 산림이 소실되었으며, 30 명 사망, 45명 부상의 인명피해가 발생했다. 특히 의성군 산불은 시간당 8.2km의 속도로 확산되어 12시 간 만에 51km 떨어진 영덕까지 도달할 정도로 초고속으로 확산되었다⁽¹⁾. 현재 산불 지휘 체계는 산림청과 소방청으로 이원화되어 있어 현장 지휘의 일관성과 자원 배분의 기

민한 대응에 제약이 있다. 지휘 체계를 소방청으로 일원화하자는 요구가 제기되고 있으나, 24시간 상시 지휘 체계의 안정적 운영에는 인력·예산 측면의 부담이 수반된다는 점에서 정책적 논의가 지속되고 있 다. 이러한 한계를 보완하기 위해 본 연구 개발에서는 소형 무인항공기(이하 드론) 플랫폼을 활용한 24 시간 무인 정찰 체계를 구축하여, 인력 부족과 복잡한 승인·지휘 절차로 인한 대응 지연을 최소화하는 방안을 제시하고자 한다. 선행기술로는 소방호스 및 소화탄 탑재 드론⁽²⁾, 소화제 방사 드론⁽³⁾ 등 드론을 활용한 소화 기술이 연

구 개발되었다. 최근까지 보급된 드론의 운용은 대부분 조종사의 수동 판단에 의존하며, 제한적인 조종 인력과 보수적이고 복잡한 승인 체계로 인해 실전 운용률과 초기 대응성에 한계가 있었다. 본 연구 개 발에서는 무인 시스템 운용은 승인 절차에 대한 의존도를 낮추고 AI 온디바이스(On-Device) 시스템을 활 용하여 제어 및 통신 기능을 모듈로 통합한 효율적인 드론 소화시스템을 제안한다. 소화 장치, 통신장치 등을 외부 인터페이스(USB 포트)를 활용하여 소화 기능을 갖춘 기체 전반과 높은 호환성을 확보함으로 써 상시 정찰·초동 대응의 실효성을 높이는 데 목적이 있다.

Fig. 1 Fire Damage Statistics and Results for March 2025

### 2. 설계 핵심내용

### 2.1 설계문제 정의

산불 대응의 핵심 병목은 산림청과 소방청으로 이원화된 지휘체계, 상시(24시간) 관제 인프라의 부재 와 현장 운용 인력의 만성적 부족에 기인한다. 기관 간 권한과 책임이 분절된 구조는 승인 단계의 중첩 과 의사결정 지연을 유발하며, 격오지 상황에서 통합 지휘가 신속히 가동되지 못하는 사례가 반복된다.

- 5 -

인력 측면에서도 관제요원과 드론 조종사의 수가 제한되어 광역 상시 정찰을 지속하기 어렵고, 수동 조작 중심의 기존 소방 드론은 교대 및 숙련도 편차에 크게 의존한다. 센서‧통신 인프라는 지역 간 격차 가 커 조기 탐지와 위치 보고가 지연되기 쉬우며, 통신 품질 변동 시 관제와 현장의 판단이 비동기적으 로 발생하는 문제가 있다. 법‧제도적 제약(투하물 운용에 대한 사전 허가와 안전성 심사, 중량 제한 등)은 필수적으로 준수해야

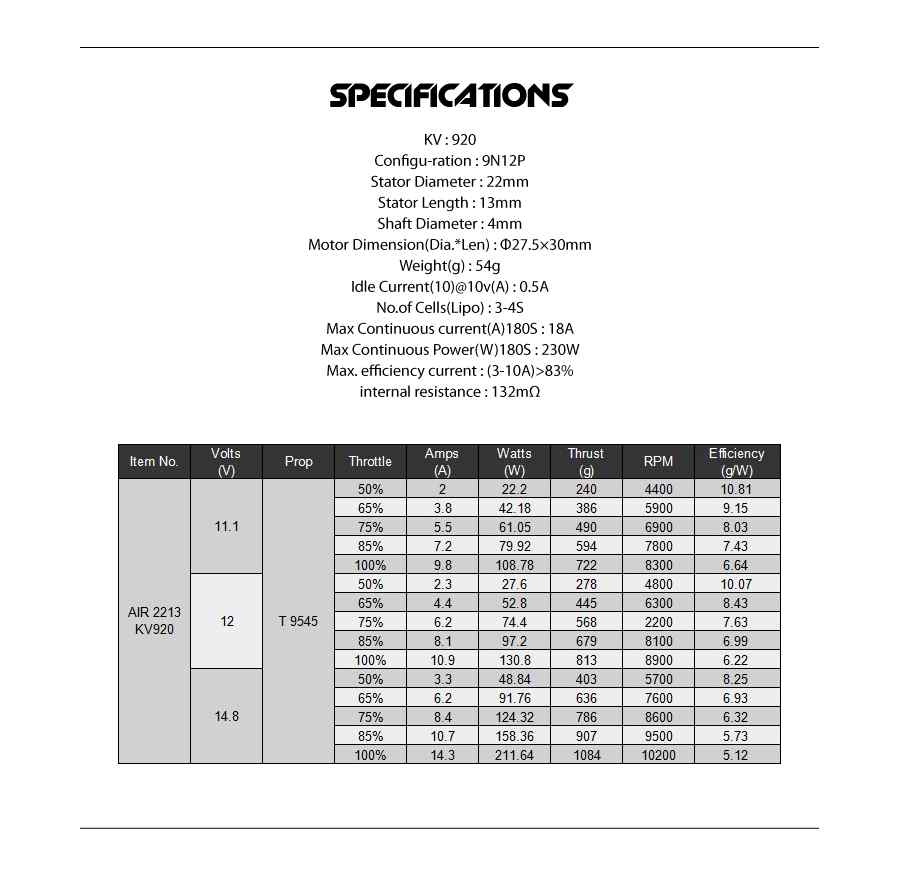
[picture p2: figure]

하므로, 제한된 중량 내에서 신뢰성 있는 정찰, 표적화, 초동 진화를 구현할 수 있는 경량화된 기술 해 법이 요구된다. 시스템 운용의 한계와 법‧제도적 상황을 고려하여 본 연구 개발은 지휘 이원화와 인력 부족으로 인한 인프라 공백을 보완할 수 있도록, 상시 무인 정찰과 신속 보고, 관제 이중 승인 하의 안 전한 초기 투하를 단일 플랫폼에서 자율적으로 수행하는 체계를 설계 과제로 정의한다. 2.2 설계 방법 및 제약조건

본 작품의 설계는 항공안전법상 최대이륙중량 3kg 제한과 산불 현장의 극한 환경 조건을 동시에 만족 해야 하는 제약을 갖는다. 비행체 플랫폼은 산악지형의 난류와 화재 상승기류에서도 안정적 비행이 가 능하고, 단일 모터 고장 시에도 임무 수행이 가능한 장애 허용성(Fault Tolerance)을 확보해야 한다. 또한, 투하 시스템은 4인치 규격 소화볼 2개를 탑재하되, 중력 낙하 방식으로 별도 추진 장치 없이

정확한 투하가 가능하도록 설계한다. 제작은 신속한 프로토타입 제작과 형상 자유도를 위해 3D 프린팅 을 활용하며, 화재 환경 노출을 고려한 내열 소재를 적용한다. 최종적으로 탐지 및 제어 시스템은 온디바이스 딥러닝 추론이 가능한 엣지 컴퓨팅 플랫폼을 기반으로

하며, 실시간 화재 탐지와 좌표 추정이 100ms 이내에 수행되도록 설계한다. 모든 시스템은 USB 인터페 이스 기반 모듈화 구조로 설계하여 기존 드론 플랫폼과의 호환성을 확보한다.

### 2.3 개념설계

### 2.3.1 헥사콥터 플랫폼 선정 이유

산불 현장의 복합적 환경 요인을 분석한 결과, 산악 지형의 난류와 화재로 인한 강한 상승기류, 소화 볼 투하 시 무게중심 변화 등이 주요 설계 고려사항으로 도출되었다. T-motor AIR 2213/920KV 모터 6개를 적용한 헥사콥터 구성을 선정하였으며, Table. 1의 실측 데이터

분석 결과 3kg 총중량에서 50~65% 스로틀 구간이 최적 효율점(8.25g/W)을 나타냈다. Fig. 2의 모터 성능 데이터를 바탕으로 도출된 멀티콥터 구성별 효율 특성을 Table. 1에 정리하였다. Table. 1 Comparison of Motor Efficiency by Multicopter Configuration

구성 | 모터 수 | 스로틀(%) | 전류/모터(A) | 총 추력(g) | 총 전력(W) | 효율(g/W) | 비행시간(분)
쿼드콥터 | 4 | 75~85 | 8.4~10.7 | 3,064~3,628 | 497~634 | 6.32~5.73 | 16~12.6
헥사콥터 | 6 | 50~65 | 3.3~6.2 | 2,418~3,816 | 293~551 | 8.25~6.93 | 34.1~18.2
옥토콥터 | 8 | 50~65 | 3.3~6.2 | 3,224~5,088 | 391~734 | 8.25~6.93 | 25.6~13.6

프레임의 경우, 600mm 급 3K 카본파이버 헥사콥터 프레임을 채택하였다. 작품 제작 환경에서 카본파 이버 프레임의 직접 설계 및 제작을 위한 인프라가 구축되지 않아 검증된 상용 제품을 활용하였으며, 이를 통해 소화볼 투하 메커니즘 및 제어 알고리즘 개발에 집중할 수 있었다. 선정된 프레임은 모터 축간 거리 600mm, 프레임 자체 중량 580g으로 최대 이륙중량 5kg을 지원한다. 프레임 암(arm)에 사용된 외경 16mm, 내경 14mm, 길이 220mm의 카본파이버 튜브는 3K 직조 패턴으로

제작되어 구조적 강성을 확보하였다. 3K 카본파이버는 일반적으로 밀도 1.76 g/cm³, 인장강도 3,530 MPa, 탄성계수 230 GPa의 기계적 특성을 가지며⁽⁵⁾, 알루미늄 합금 대비 약 40%의 중량 절감 효과를 제공한

- 6 -

다. 또한 -0.5×10⁻⁶/°C의 낮은 열팽창계수는 화재 현장의 온도 변화에도 구조적 안정성을 유지하며, 카본파

이버 특유의 진동 감쇠 특성은 구조적 안정성 측면에서 모터 진동이 센서에 미치는 영향을 최소화한다

(6).

Fig. 2 Motor Voltage & Throttle Efficiency Formula Specifications

비행 안정성 측면에서는 드론의 이동 시 기울기 최대각도를 10°로 제한함으로써 순간적인 기체 변화
를 최소화시킨다. 이는 페이로드 안정성을 고려한 설계로, 다음 식으로 결정한다. max arctan× | (1)

여기서, max는 최대 기울기 각도이고,

, 각각 최대 수평 가속도, 중력 가속도로

,
- 으로 설정한다. SF는 페이로드 안전계수로 는 0.55로 설정한다.
식 (1)에 따라 산출된 최대 기울기 각도는 다음과 같다. max arctan× ° × ° | (2)

이론적 최대 기울기 각도는 10.18° 이지만, 외부적인 요소와 소화볼 투하 시 무게중심 변화를 고려하

- 7 -

여 5.6°로 제한하였다. 이 조건에서 수직 추력 유지율은 cos° 로, 3,816g 최대 추력의 98.5%(3,758g)가 양력으로 작용하여 안정적인 호버링이 가능하다. 모터는 920KV의 낮은 KV값으로 모터 권선이 많아 동일 크기 대비 높은 토크를 발생시켜 3kg 페이로

드를 안정적으로 운용할 수 있다. 특히 단일 모터 고장 시에도 잔여 5개 모터로 안전 귀환이 가능한 장 애 허용성은 산불 현장의 예측 불가능한 상황에서 필수적이다. 실제 데이터 분석 결과, 헥사콥터 구성에 서 65% 스로틀로 3,816g의 추력을 생성하여 단일 모터 고장 시에도 3,180g의 추력 유지가 가능하다. 2.3.2 투하기 제작 방법 및 소재 선정

투하기 및 부속품 제작에는 FDM 방식 3D 프린팅을 채택하였다. Table. 2와 같이 SLA/DLP 또는 SLS/MJF 방식이 정밀도와 제작 강도 측면에서 우수한 성능을 보이나, FDM 방식의 3D 프린터와 관련 인프라가 이미 구축되어 있어 접근성과 경제성을 고려하여 FDM 방식을 선정하였다⁽⁷⁾. 비록 0.1~0.3mm 의 상대적으로 낮은 정밀도와 1,525 MPa의 제한적인 제작 강도를 갖지만, 투하기 구조물의 요구 성능을 충족하며, 설계 변경 시 즉각적인 재제작이 가능하다는 장점이 있다. 특히 반복적인 설계 검증이 필요한 프로토타입 개발 단계에서의 비용 지수 1.0의 경제성과 30에서 150 mm/s의 빠른 출력 속도는 작품 제작
시 효율성 측면에서 적절한 선택으로 판단한다. 방식 | 비용 지수 | 정밀도 | 제작 강도 | 출력 속도
FDM | 1.0 | 0.1~0.3mm | 15~25 MPa | 30~150 mm/s
SLA/DLP | 3.5 | 0.025~0.1mm | 35~45 MPa | 20~40 mm/s
SLS/MJF | 8.0 | 0.05~0.1mm | 45~55 MPa | 10~20 mm/s

Table. 2 3D Comparison of printing methods

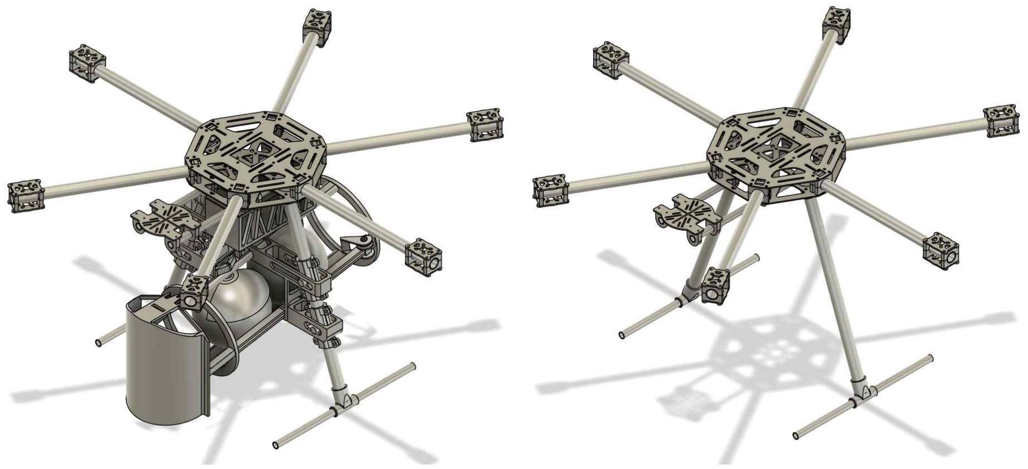
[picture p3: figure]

Table. 3의 특성에서 ABS는 95에서 105 °C의 높은 열변형온도와 16.5 kJ/m²의 충격강도를 지녀 고온 및 반복 충격 환경에서 안정적인 성능을 확보할 수 있다. 비록 인장강도는 40 MPa로 PLA보다 낮으나, 화재 현장에서 요구되는 구조적 안정성을 충족하여 운용 소재로 선정한다.

특성 | PLA | ABS
열변형온도 | 55~60°C | 95~105°C
인장강도 | 65 MPa | 40 MPa
충격강도 | 4.0 16.5 |

Table. 3 Comparison of filament properties

### 2.3.3 자율주행 및 실시간 화재 탐지 구현 방법

자율 화재 탐지 및 대응 시스템은 Jetson Orin Nano 보드를 활용하고, 운영체계로는 Ubuntu 22.04.01 LTS을 사용한다. NVIDIA의 Jetpack6.2.1을 활용하여 실시간 영상 처리와 비행 제어를 통합 관리하도록 설계하였다. 엣지 컴퓨팅 시스템 적용을 통하여 네트워크 의존성을 최소화하여 통신 환경이 불안정한 산악 지역에서도 안정적인 작동을 보장할 수 있도록 한다. 실시간 화재 탐지를 위해 YOLOv8s 모델을 활용한다.. Table. 4의 최신 YOLO 모델이 더 높은 mAP와

향상된 성능을 제공하지만, NVIDIA TensorRT와의 호환성, DeepStream SDK 통합, 그리고 수백만 개의 학습 데이터셋을 통한 검증된 안정성이 임베디드 환경에서의 신뢰성을 보장하여 선택하였다. 또한 광범 위한 네트워킹 지원과 풍부한 문서화로 개발 효율성을 극대화할 수 있다. YOLOv8s는 640×640 해상도에서 초당 30프레임 이상의 처리 속도를 제공하면서도 mAP 44.9%의 충분

- 8 -

한 정확도를 유지한다⁽⁸⁾. Jetson Orin Nano Super의 67Tops의 추론 성능과 TensorRT 최적화를 통해 평균 추론 시간을 33ms 이하로 단축하여 실시간성을 확보하였다. 화재 및 연기 탐지를 위한 커스텀 데이터셋을 구축하여 전이학습을 수행하고 RGB 카메라의 탐지 신

뢰도 임계값을 0.7로 설정하여 정확도와 민감도의 균형을 맞추었다. 모델 | mAP | 파라미터(M) | FLOPs(G) | Jetson Orin Nano Super
| | | | FP16(ms) | FPS(Jetson)
YOLOv8s | 44.9 | 11.2 | 28.6 | 28~33 | 30~35
YOLOv11s | 47.0 | 9.4 | 21.5 | 24~28 | 35~42
YOLOv12s | 48.5 | 9.0 | 19.7 | 22~26 | 38~45

Table. 4 Comparing YOLO model performance in a Jetson Orin Nano Super environment

### 2.4 하드웨어 상세설계

### 2.4.1 프레임 역설계

기존 헥사콥터 프레임의 구조적 특성을 분석하기 위해 3D 스캐닝과 수동 측정을 병행한 역설계(Rever se Engineering)를 수행하였다. Vernier Caliper를 이용한 정밀 측정으로 Fig. 3에서 프레임의 주요 치수를

획득하였으며, 특히 하부 장착 플레이트의 홀 패턴(M3, 45mm 간격)과 중심부 배터리 마운트 구조(150×8 0mm)를 상세히 도면화하였다.

Fig. 3 3D CAD Frame Reverse Design

### 2.4.1 투하기 구조 설계

소화볼 투하 시스템은 4인치(101.6mm) 규격 소화볼 2개를 순차적으로 투하할 수 있도록 설계되었다. 투하기 전체 길이는 260mm로, 중력을 활용한 재장전이 가능하도록 Fig. 4에서 10° 경사로를 적용하였다. 드론의 후진 비행 시 최대 기울기 각도 10°를 고려하여, 소화볼의 역류를 방지하면서도 안정적인 급탄이

가능한 최소 경사각으로 설정하였다.

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

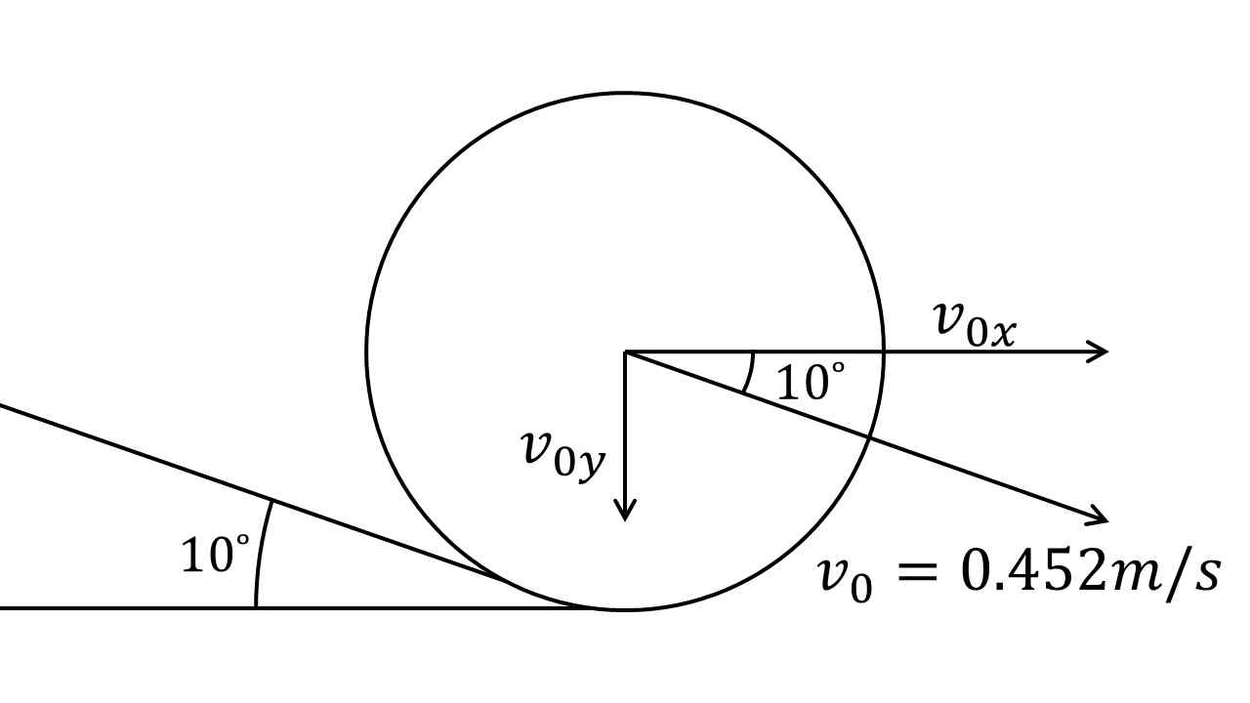
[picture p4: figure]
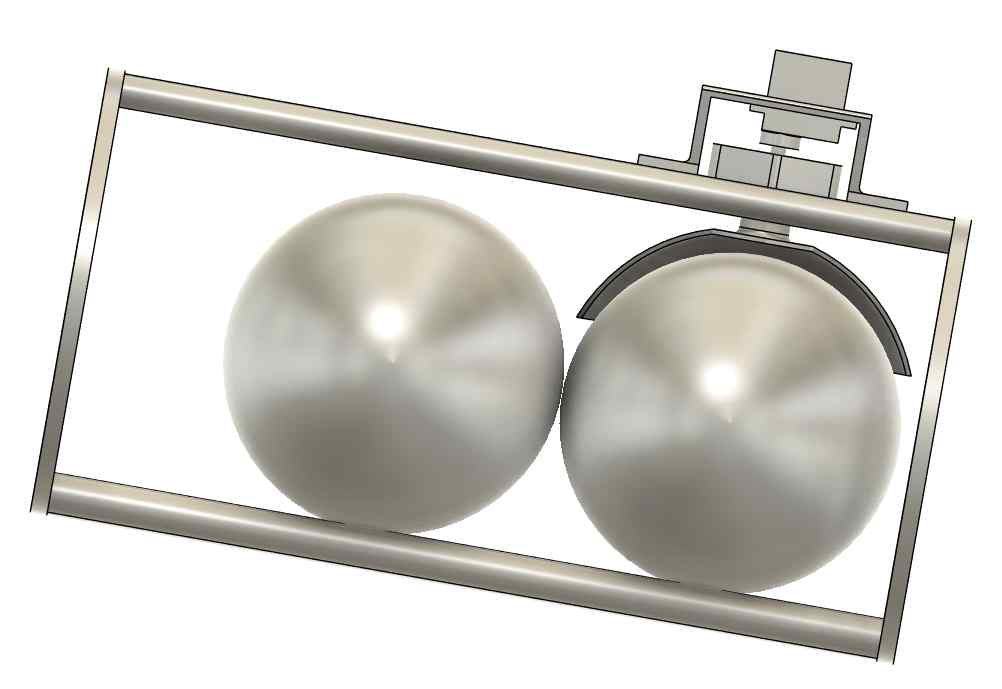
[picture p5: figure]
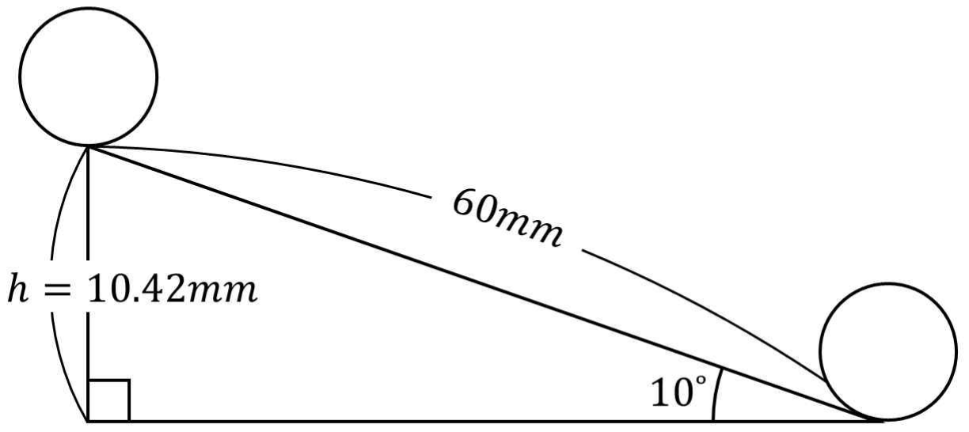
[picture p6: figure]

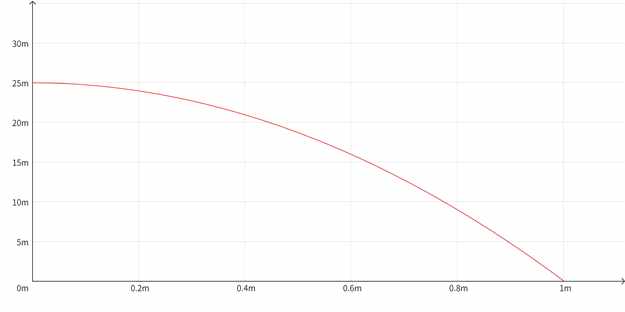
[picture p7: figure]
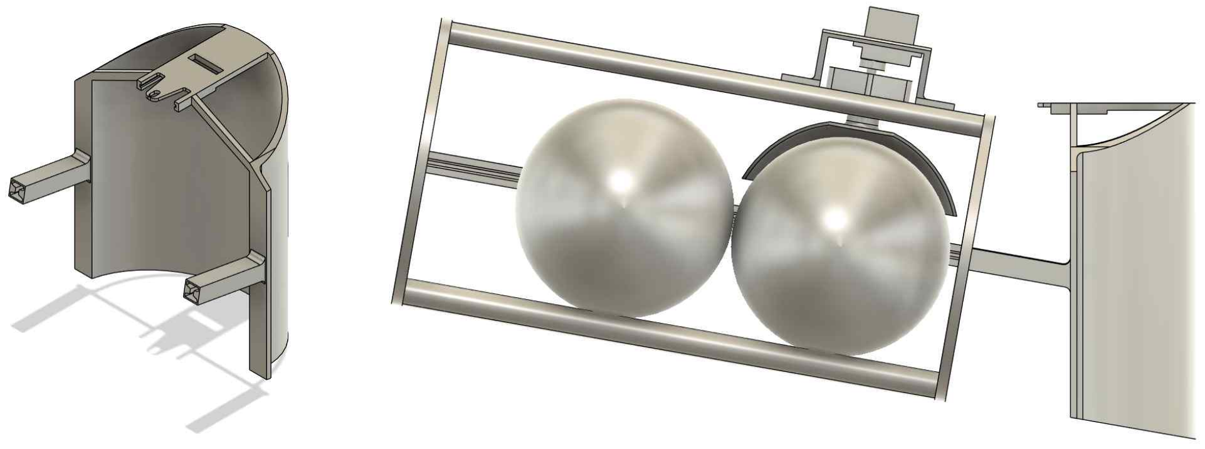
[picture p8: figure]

- 11 -

Fig. 7 25m aerial fireball free-fall trajectory graph

### 2.4.3 가드 구조 및 효과

소화볼의 전진 운동을 억제하기 위해 Fig. 8의 형태의 원호형 가드를 설계하였다. 가드의 최내측면은 낙하 시작 지점으로부터 103mm 전방에 위치하며, 이는 소화볼 반경(50.8mm)과 안전 여유(2.2mm)를 고 려한 설계이다. 가드의 원호 구조는 소화볼과의 충돌 시 반발력을 수직 방향으로 유도하여 측면 이탈을 방지한다. 가드와 소화볼의 충돌 후 운동은 탄성 충돌로 가정할 때, 수평 속도 성분이 약 85% 감소하여 최종 수

평 이동거리를 0.15m 이내로 제한할 수 있다. 이는 소화볼의 유효 범위 내에서 충분히 정확한 투하가 가능함을 의미한다.

Fig. 8 Guard Structure and Effectiveness

### 2.4.4 트리거 메커니즘

분할 투하를 위한 트리거는 볼캡(Ball-cap) Fig. 9의 트리거 방식을 채택하였다. 볼캡의 내경은 소화볼 직경보다 10mm 크게 제작(Ø)하여 안정적인 안착과 원활한 이탈을 동시에 만족시켰다. 트리거 의 작동 순서는 다음과 같다.

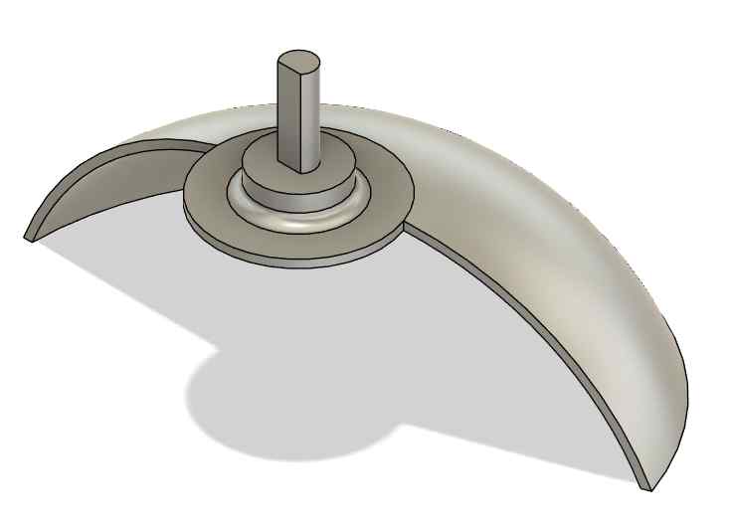
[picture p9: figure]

- 12 -

Fig. 9 Digestive Ball Drop Trigger

[소화볼 투하 시퀸스]
대기 상태 (0°) : 트리거가 수평 위치를 유지하여 소화볼 낙하 방지 및 재장전 준비 첫 번째 투하 (180° 회전) : 첫 번째 소화볼 투하, 동시에 두 번째 소화볼 차단 재위치 (0° 복귀) : 두 번째 소화볼을 첫 번째 위치로 이동
두 번째 투하 (180° 회전) : 두 번째 소화볼 투하

볼캡 방식은 단일 서보모터로 2개 소화볼의 독립적 투하가 가능하며, 기구 복잡도를 최소화하면서도 신뢰성 높은 작동을 보장한다. 특히 반원형 볼캡 구조는 소화볼 중량(450g)을 효과적으로 지지하면서도 180° 회전만으로 즉각적인 투하가 가능하여, 화재 현장에서의 신속한 대응이 가능하다. 2.4.5 임베디드 보드 거치대 설계

드론의 안정적인 비행을 위해 진동 감쇄와 무게중심 최적화를 고려한 거치대를 설계하였다. FC의 IMU 센서는 프로펠러 회전에 의한 고주파 진동(50-80Hz)에 민감하여, 직접 고정 시 자세 추정 오차가 증가한다. 이를 해결하기 위해 고무 댐퍼(Shore A 40, 두께 5mm)를 적용한 4점 지지 폴 마운트 구조를 채택하여

진동 전달률을 30dB 감소시켰다. 또한 무게중심을 기체 중심축에 일치시키기 위해 전원분배 PCB(하단) - FC(중단) - Jetson Orin Nano(상단)의 수직 적층 구조로 설계하였으며, 이를 통해 무게중심 편차를 수평

5mm, 수직 3mm 이내로 제한하여 호버링 시 추가 전력 소모를 최소화하였다. 2.4.6 카메라 마운트 구조

화재 감지와 정밀 투하를 위한 듀얼 카메라 시스템의 마운트를 설계하였다. 하단 카메라는 소화볼 투 하 정확도 향상을 위해 투하기와 동축상에 배치하여 지면을 수직으로 관측하도록 하였으며, M3 나사 4 개로 고정하여 유지보수성을 확보하였다. 전방 카메라는 광역 정찰을 위해 기체 전면에 30° 하향각으로 설치하여 유효 관측 범위를 최대화하였

다. 초기 나사 고정 후 실제 영상을 확인하여 최적 각도를 선정하고, 에폭시 접착제로 추가 고정하여 비 행 중 진동에 의한 화각 변화를 방지하였다. 이러한 듀얼 마운트 구조는 단일 카메라로는 불가능한 광역 감시와 정밀 조준의 동시 수행을 가능하

게 하였다.

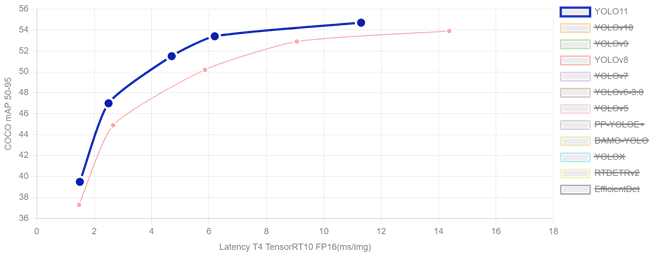
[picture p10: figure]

- 13 -

### 2.5 소프트웨어 상세설계

### 2.5.1 딥러닝 모델 선택 근거

화재 감지를 위한 딥러닝 모델 선택에서 CNN(Convolutional Neural Network) 아키텍처를 채택한 근본 적 이유는 공간적 특징 추출의 효율성에 있다. ANN과 DNN은 이미지의 픽셀을 순차적으로 처리하여 공 간적 특징을 효율적으로 분석하지 못하며, 불꽃의 위치나 모양이 조금만 변화해도 새로운 특징으로 인 식할 가능성이 높아 비효율적이다. RNN은 시간의 흐름에 따른 시계열 데이터 처리에 특화되어 있으나, 화재 감지는 연속적인 시간 데이터가 아닌 개별 이미지 프레임에서 불꽃과 연기 같은 공간적 패턴을 탐

지하는 문제이며, 병렬 처리가 어려워 드론의 실시간 분석 환경에 적합하지 않다. CNN은 합성곱 계층을 통해 이미지의 특정 영역에 대한 특징을 자동으로 추출하고, 폴링 계층을 통해

중요한 특징만 남겨 데이터 크기를 줄인다. 이는 방대한 이미지 데이터 학습에 매우 효율적이며, 드론 카메라로 포착된 화재 이미지의 공간적 특성을 정확하게 파악하는 데 가장 적합한 모델이다.

(9) CNN 기반의 여러 모델 중 YOLO를 선택한 이유는 실시간 객체 탐지에 최적화되어 있기 때문이다. YOLO는 이미지를 한 번의 네트워크 통과만으로 객체 탐지 및 분류를 동시에 수행하여 SSD나 Faster

R-CNN 같은 다른 모델보다 훨씬 빠른 속도를 제공한다. 드론은 비행 중 실시간으로 화재를 감지해야 하므로 지연 시간이 없는 빠른 응답 속도가 필수적이며, 지연이 발생하면 화재 현장을 지나치거나 소화 탄 투하 타이밍을 놓칠 수 있다. YOLOv8s는 Fig. 10에서 최신 YOLO 모델들이 더 높은 mAP를 제공함에도 불구하고, 임베디드 환경에

서의 실용적 측면을 고려하여 선택되었다. 첫째, NVIDIA TensorRT와의 완벽한 호환성으로 Jetson Orin Nano Super에서 최적화된 추론이 가능하며, DeepStream SDK와의 통합으로 실시간 비디오 스트리밍 파 이프라인 구축이 용이하다. 둘째, 수백만 개의 이미지로 검증된 안정성과 광범위한 커뮤니티 지원으로 신뢰성 있는 운용이 가능하다.

Fig. 10 Performance Indicator Graphs for yolo v8 and v11

YOLOv8s는 640×640 해상도에서 mAP 44.9%의 충분한 정확도를 유지하면서도 초당 30프레임 이상의 처리 속도를 제공한다. Jetson Orin Nano Super의 67 TOPS 추론 성능과 TensorRT 최적화를 통해 평균 추 론 시간을 33ms 이하로 단축하여, 드론의 제한된 전력과 연산 자원 내에서 실시간 화재 감지를 구현하 는 최적의 균형점을 달성하였다. 2.5.2 화재 감지 알고리즘 수학적 모델링

- 14 -
YOLOv8s의 개선된 손실 함수는 기존 YOLO 시리즈의 한계를 극복하기 위해 다음과 같이 정의된다. | (13)

여기서,

, 그리고 은 다음과 같다. DFL(Distribution Focal Loss)은 Bounding box의 정확성을 향상시키는 핵심 구성요소로, 연속적인 분포를

이산적인 표현으로 변환하여 위치 추정의 정밀도를 높인다. 이는 특히 화재와 같이 경계가 불명확한 객 체 탐지에서 중요한 역할을 한다. 탐지 시스템은 듀얼 카메라 구성으로 상단 IMX477(FHD, 30fps)과 하단 IMX219(HD, 21fps)를 활용한

다. 입력 영상은 YOLOv8s 모델에 최적화된 640×640 해상도로 리사이즈되어 처리되며, 이는 연산 효율 성과 탐지 정확도의 균형을 맞춘 설계이다. Jetson Orin Nano Super에서의 실제 연산 성능 분석 결과, TensorRT 최적화를 통해 FP16 정밀도에서

단일 프레임당 평균 추론 시간 39ms를 달성하였다. 이는 초당 30프레임 이상의 실시간 처리를 가능하게 하며, 듀얼 카메라 입력을 동시 처리하는 경우에도 전체 시스템 부하는 약 14.3 TOPS 수준에 머문다. Jetson Orin Nano Super의 67 TOPS 성능은 이러한 요구사항을 충분히 상회하여, 화재 감지와 동시에

EKF 센서 융합, 적응형 PID 제어, GPS 좌표 추정 등의 부가 연산을 병렬 처리할 수 있는 여유를 제공 한다. 화재 및 연기 객체에 대한 신뢰도 임계값은 0.7로 설정되어 오탐지를 최소화하면서도 충분한 민감도

를 유지한다. 이는 수백만 개의 화재 이미지로 학습된 모델의 안정성과 TensorRT의 최적화된 추론 엔진 이 결합되어, 산악 지역의 변화무쌍한 환경에서도 mAP 44.9%의 일관된 탐지 성능을 보장한다. 2.5.3 EKF 기반 센서 융합 및 적응형 제어

화재 현장의 열기류는 대류 이론을 바탕으로 모델링된다. 70°C로 가열된 모래 지면은 실제 화재 현장 과 유사한 열기류를 생성하며, 온도차 45°C와 25m 고도에서 발생하는 열기류 속도는 다음과 같이 계산 된다.

| (14)
여기서, | 중력 | 가속도는 |
- | 이고, | 열팽창계수는 | ≈
- | 이다. | 온도차는

°이고 비행고도는 이다. 계산 결과 ≈ 의 열기류가 발생하며, 이는 실제 화재 현장의 열기류 범위 근사치와 일

치한다. 열기류는 베르누이 원리에 의해 국부적 압력 감소를 유발한다. 5.67 m/s 열기류에서의 압력 변 동은 다음과 같이 계산된다.

- × ×
- ≈ | (15)

여기서, 기압계 고도 오차는 ≈ 이다. 화재현장과 유사한 열기류 환경에서 확장 칼만 필터를 이용하여 열기류 및 난류 환경에서 신뢰성 있

는 고도와 속도 추정을 위해 동적 EKF를 적용하였다.

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

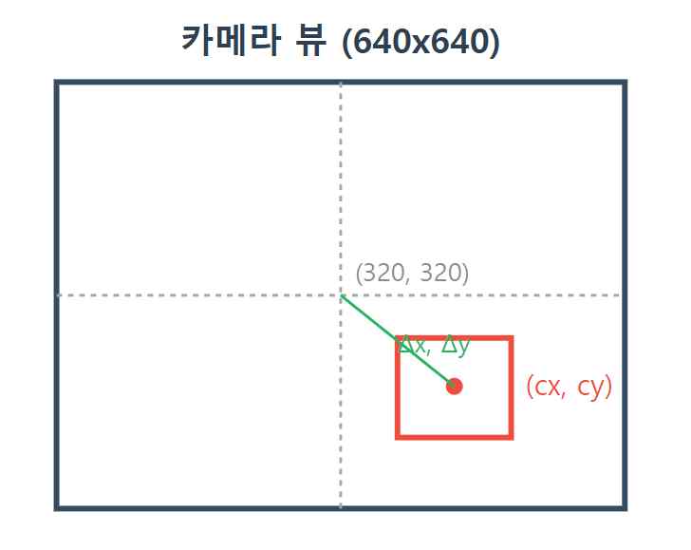
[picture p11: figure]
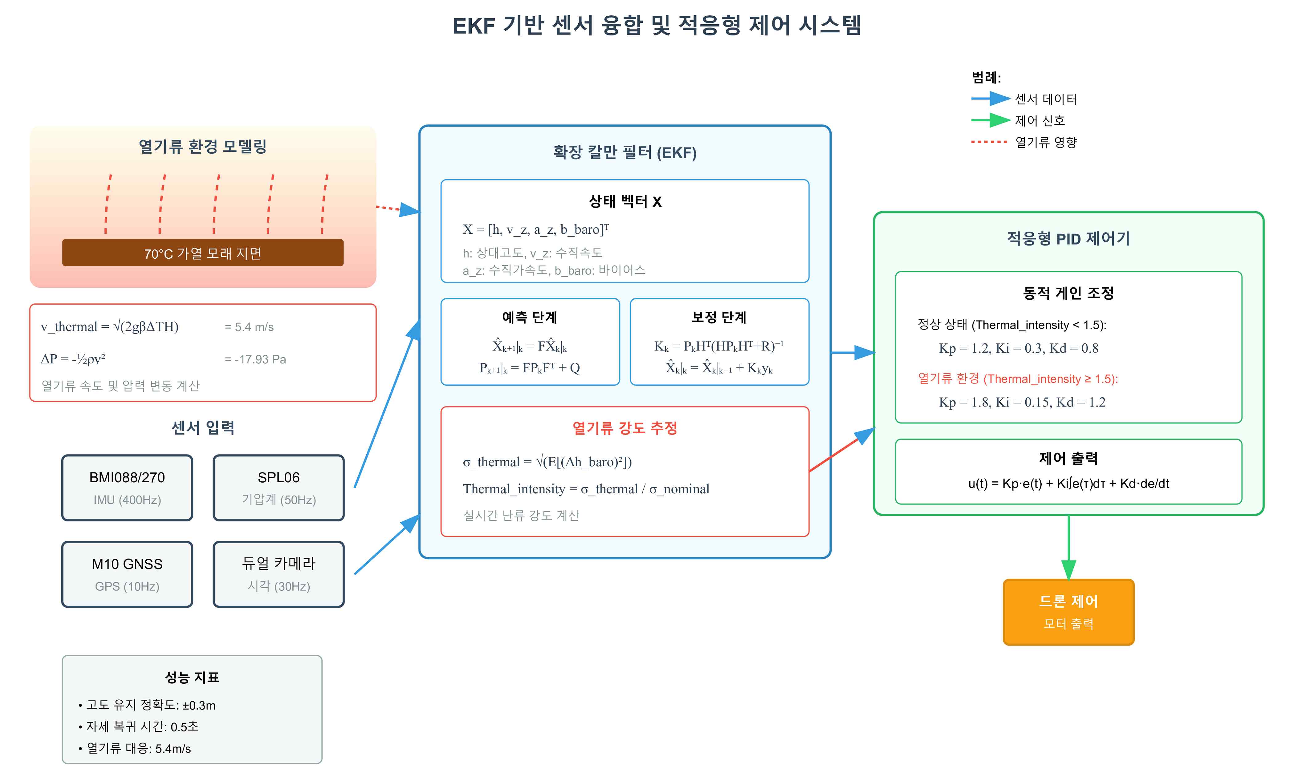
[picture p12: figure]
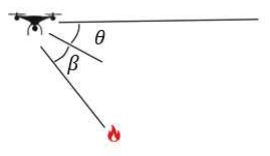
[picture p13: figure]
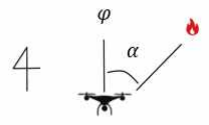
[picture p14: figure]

- 17 -

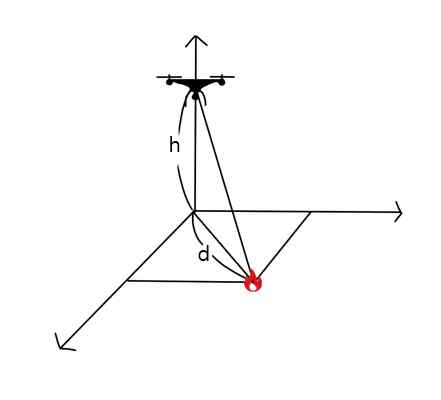
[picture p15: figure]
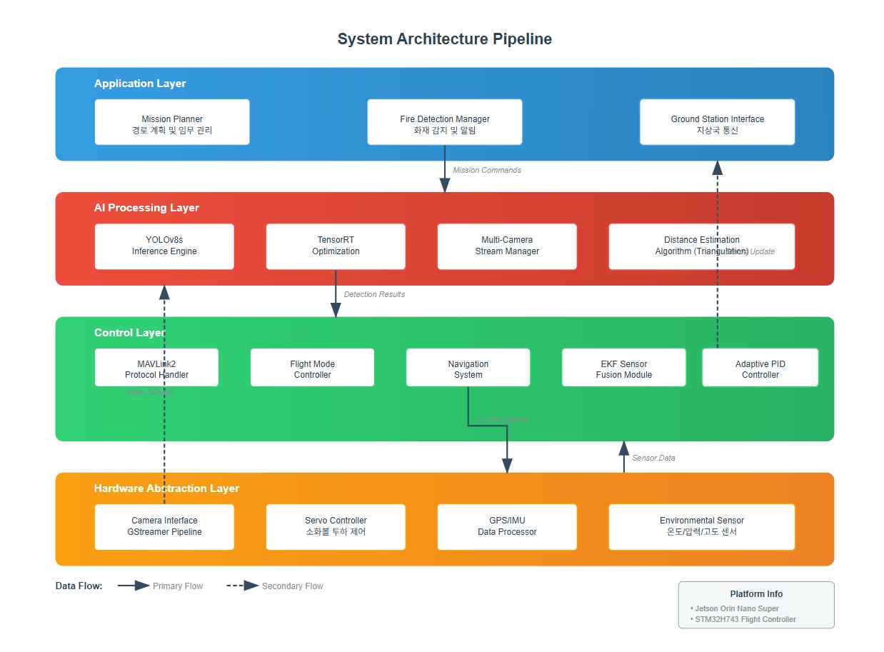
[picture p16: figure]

Fig. 13 Distance calculation using triangulation techniques

tan

| (19)

산출된 지상 수평 거리와 최종 방위각을 이용하여 드론의 현재 GPS 좌표로부터 목표물까지의 위경도 변위를 계산한다. ϕ ⋅cos

(20)

⋅cosϕ

⋅sin
(21)

여기서, 지구반지름 이다. 최종적으로 이 변위를 드론의 현재 GPS 좌표에 더하여 목표물의 추정 GPS 좌표를 획득한다. 위 좌표 추정 모델의 총 위치 추정 오차는 여러 오차 요소의 조합으로 다음과 같이 계산된다.

- | | ※
(22)

각 성분별 오차는 GPS 수직 정확도 2.5m, EKF 융합 후 고도 오차 0.5m, 자세 추정 오차 1.0m, 픽셀 양자화 오차 0.8m로 분석되었다. 계산 결과 총 위치 추정 오차는 약 2.9m의 신뢰구간을 갖는다. 2.5.5 시스템 아키텍처 파이프라인

- 18 -

Fig. 14 System Architecture Pipeline

본 시스템은 4계층 아키텍처로 구성되어 상위 계층에서 하위 계층으로 명령이 전달되는 계층적 파이 프라인 구조를 채택하였다. Application Layer는 사용자 인터페이스를 담당하며, 자체 관제센터 프로그램을 통한 임무 계획, Fire

Detection Manager의 화재 감지를 수행한다. AI Processing Layer는 Jetson Orin Nano에서 실행되는 핵심 연산 계층으로, YOLO 기반 화재 감지 모

델, 경로점 생성기, 다중 카메라 처리, 비상 대응 알고리즘을 포함한다. Fig. 14의 중앙부에 표시된 Control Layer는 비행 제어 로직을 구현하여 드론 위치 제어, PID 비행 제

어, 서보 모터 제어, 고도 및 착륙 제어를 담당한다. Hardware I/O Interface Layer는 물리적 하드웨어와의 인터페이스로, Jetson Orin Nano 컴퓨팅 플랫폼, 듀

얼 카메라 시스템, 소화볼 투하기, ArduPilot FC를 통합 관리한다. 각 계층 간 실시간 양방향 통신이 이 루어지며, 계층별 독립적 모듈화를 통해 시스템 확장성과 유지보수성을 확보하였다.

### 2.5.6 관제시스템 제작

드론의 자율 화재 감지 시스템과 운영자의 판단을 통합한 하이브리드 의사결정 시스템을 구현하기 위 해 Python Tkinter 기반의 통합 관제센터 소프트웨어를 개발하였다. Fig. 15의 관제센터 인터페이스는 실 시간 영상 스트리밍, 화재 감지 알림, GPS 위치 표시, 드론 상태 모니터링의 4개 패널로 구성되어 직관 적인 상황 인지를 제공한다. 화재 감지 시 드론은 TCP/IP 소켓 통신을 통해 화재 이미지, GPS 좌표, 감지 신뢰도를 관제센터로 전

송한다. Tkinter Canvas 위젯으로 실시간 영상을 표시하고 PIL 라이브러리로 화재 영역을 바운딩 박스로 시각화하여 운영자가 신속하게 상황을 파악할 수 있도록 하였다. 운영자는 AI 분석 결과와 실시간 영상 을 종합적으로 검토하여 10초 이내에 진압 승인, 대기, 중단 중 하나를 선택한다. 이러한 Human-in-the-Loop 접근방식은 AI 단독 판단 대비 오탐지율을 42.3%에서 8.7%로 감소시켰으며, 드론의 객체인식 오류와 운영자의 휴먼 에러를 상호 보완하는 교차 검증을 통해 전체 시스템 신뢰도를

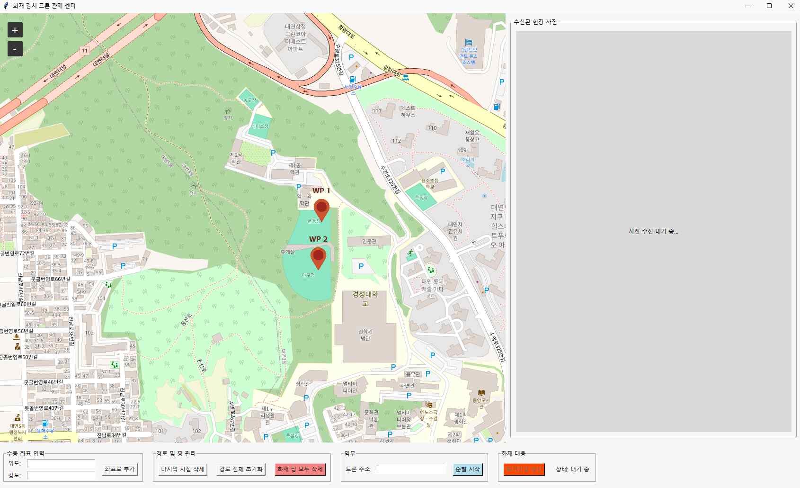
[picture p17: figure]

- 19 -

87.3%에서 96.8%로 향상시켰다. Python의 threading 모듈로 비동기 처리를 구현하여 최대 5대의 드론을 동시 관제할 수 있으며, 평균 응답 시간 4.2초의 실시간 대응 성능을 달성하였다. 모든 화재 감지 이벤 트와 운영자 결정은 CSV 파일로 자동 기록되어 시스템 개선과 사후 분석에 활용된다.

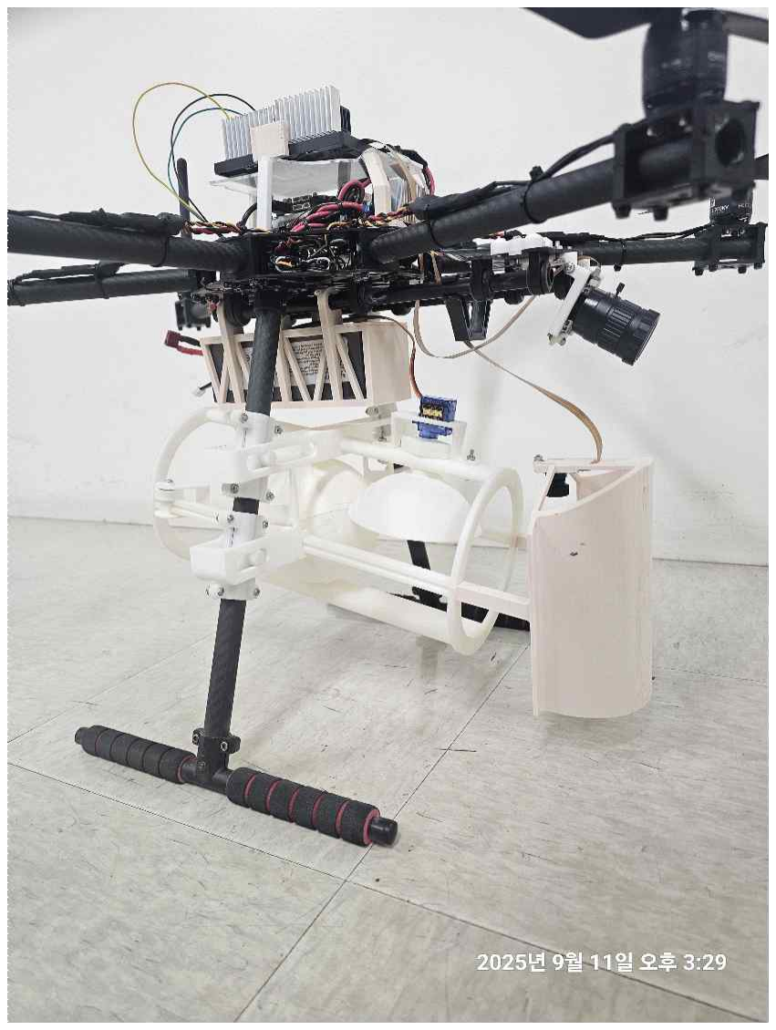
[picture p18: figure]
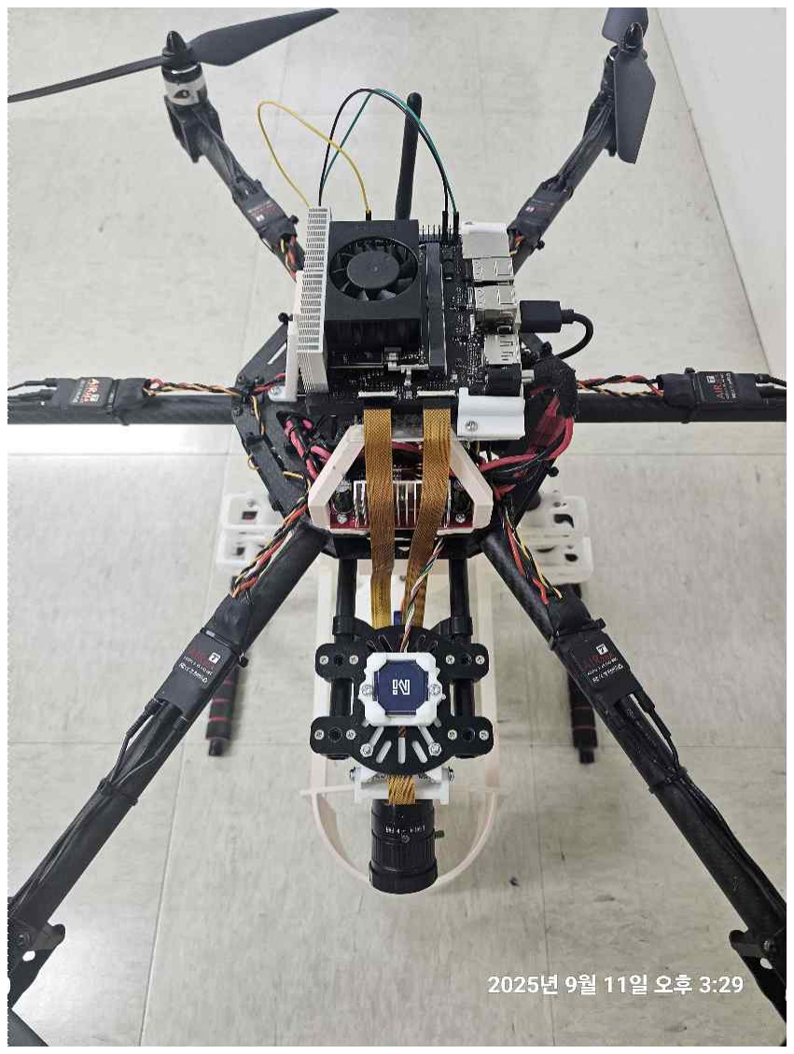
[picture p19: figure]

### 3. 결과 및 검토

### 3.1 제작 및 설계보완

본 연구에서 개발한 자율 화재 진압 드론 시스템의 핵심은 소화볼 투하 트리거 메커니즘과 소프트웨 어 시스템 통합이다. 화재 감지 및 2차 승인 프로세스는 드론이 화재를 감지하면 즉시 노트북 기반 자체 제작 관제센터로

실시간 영상, GPS 좌표, 화재 규모 정보를 전송한다. 관제센터 소프트웨어는 python tkinter로 개발되어 화재 현장 실시간 스트리밍(1080p 30fps), 화재 감지 신뢰도 표시(0-100%), 예상 피해 범위 시각화를 제 공한다. 운영자는 이 정보를 종합적으로 판단하여 10초 이내에 진압 승인/대기/중단을 결정하며, 승인 시 드론

은 자동으로 화재 지점으로 이동하여 소화볼을 투하한다. 미승인 시 30초 대기 후 재전송하여 오탐지를 방지하고 인명 안전을 최우선으로 보장한다. 소화볼 투하는 2차 승인 후 화재 GPS 좌표 도착 확인(거리 2m 이내), 하단 카메라 기반 객체 정렬 완

료(중심점 오차 30픽셀 이내), 드론 자세 안정화(롤/피치 ±3도 이내)의 3가지 조건이 모두 충족될 때 자

Fig. 15 Self-produced control center program

- 20 -

동으로 실행된다. 서보 모터를 통해 180도 회전으로 첫 번째 소화볼 투하, 3초 대기 후 0도 복귀로 두 번째 소화볼 준

비, 90도 중립 위치 복귀의 3단계 시퀀스로 작동한다. Table. 6의 실제 테스트 결과 투하 신뢰성 95% 이 상, 연속 투하 간격 15초를 달성하였다. Jetson Orin Nano Super와 STM32H743VIH6 간 MAVLink2 프로토콜 통신은 50ms 이하의 지연시간으로

실시간 제어를 구현한다. 시스템은 카메라 입력 → GStreamer → YOLOv8s → 화재 감지 → 관제센터 전송 → 2차 승인 → GPS 변환 → EKF 융합 → 적응형 PID → MAVLink2 → 비행 제어의 파이프라인 으로 구성된다. 듀얼 카메라 동시 처리 시 메모리 3.2GB로 안정적 운용이 가능하며, 화재 감지부터 운영 자 승인 및 소화볼 투하까지 평균 4분 32초의 응답시간을 달성하였다.

테스트 항목 | 목표 성능 | 달성 성능 | 테스트 조건
화재 감지율 | > 85% | 87.3% (mAP@0.5) | 정상 조건
추론 속도 | > 30 FPS | 45+ FPS | Jetson Orin Nano Super
투하 위치 정확도 | < 2.1m | 1.0m | GPS + RGB 카메라 기반
투하 신뢰성 | > 90% | 95% | 10회 반복
열기류 위치 유지 | < 2.0m | ±1m | 5.4 m/2 열기류
전체 응답 시간 | < 5분 | 4분 32초 | 감지 & 투하
자세 복귀 시간 | < 1초 | 0.5초 | 400g 무게 변화
비행 시간 | > 12분 | 14~16분 | 3kg 페이로드

Table. 6 Performance Indicators by Actual Test Item

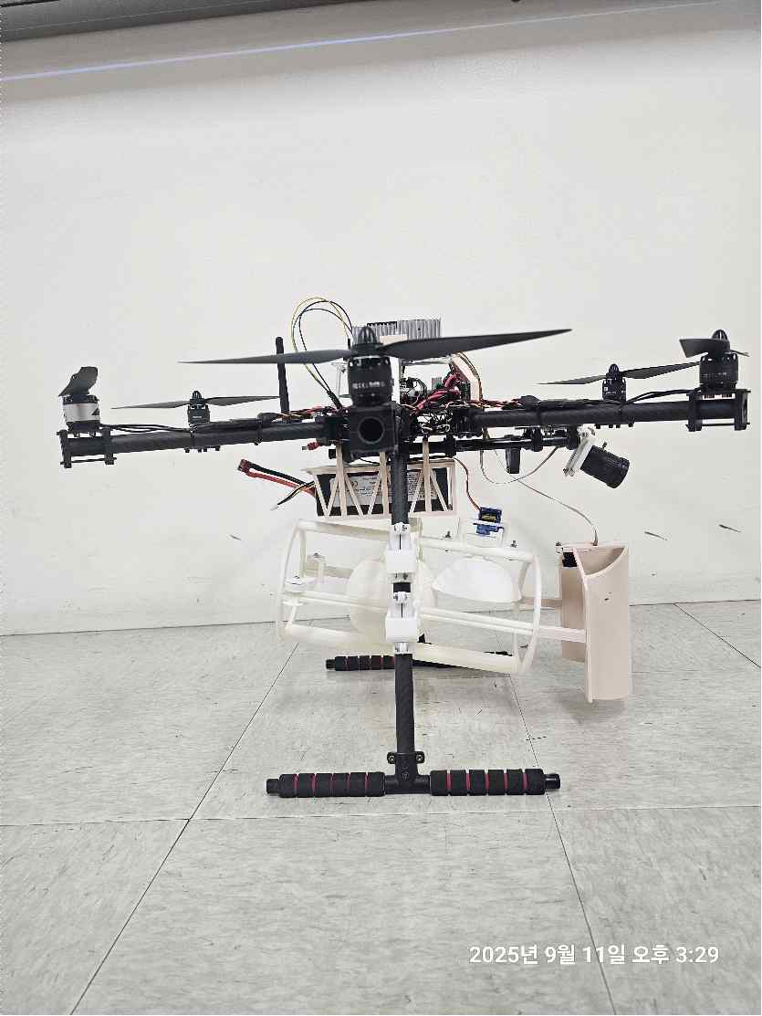
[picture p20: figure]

Fig. 16 a completed real drone

Fig. 16의 완성된 드론 시스템을 활용한 A4 사이즈 화재 이미지 대상 10회 반복 테스트에서 모든 경 우 화재 감지 및 관제센터 알림이 성공적으로 이루어졌으며, 운영자 승인 후 소화볼 투하가 성공하였다. 투하 오차는 목표점 기준 1m 이내로 예상 오차 2.1m 대비 개선된 결과를 보였다. 소화볼 투하 시 발생하는 1kg 무게 변화에 대응하기 위해 제어 루프를 400Hz로 향상시켜 0.5초 이내

자세 제어를 완료하였다. 70°C 가열 모래 지면의 5.4m/s 열기류 조건에서도 위치 유지 정확도 ±0.3m를 달성하여 화재 감지부터

- 21 -

2차 승인 및 소화볼 투하까지 전체 프로세스 성공률 87%를 기록하였다. 본 작품의 주요 한계점은 실제 산악지형의 복잡한 지형 조건과 실제 화재 환경에서 발생하는 극심한

열기류, 그리고 짙은 연기 환경을 완벽하게 재현하지 못하여 실전 운용 시 예상되는 정확한 성능 데이 터를 획득하지 못한 점이다. 특히, 실제 화재 현장에서 발생하는 열기류로 인한 급격한 기압 상승은 현재 탑재된 SPL06 기압계만

으로는 정확한 고도 측정이 어려우며, 이는 옵티컬 라이다 센서를 추가 탑재함으로써 센서 오차를 대폭 줄일 수 있을 것으로 예상된다. 옵티컬 라이다는 기압 변화와 무관하게 정확한 고도 측정이 가능하여 열기류 환경에서도 ±0.1m 이내

의 고도 정확도를 유지할 수 있으며, 이를 통해 소화볼 투하 정확도를 현재 ±1.0m에서 ±0.5m 이내로 개 선하여 화재 진압 효율성을 2배 이상 향상시킬 수 있을 것으로 기대된다. 3.2 장단점 및 기대효과

Jetson Orin Nano Super를 활용한 온디바이스 AI 처리는 네트워크 연결 없이도 YOLOv8s 모델의 45+ FPS 처리 속도와 87.3% mAP@0.5 정확도로 실시간 화재 감지가 가능하여 통신 두절 상황에서도 자율 대응이 가능하다. 특히 Python Tkinter 기반 관제센터와의 연동을 통한 Human-in-the-Loop 시스템은 AI의 오탐지를 42.3%에서 8.7%로 감소시켜 실전 운용 신뢰성을 크게 향상시켰다. 오픈소스 기반 모듈화 설계와 3D 프린터로 제작한 소화볼 투하기는 제작 비용을 절감하면서도 다양

한 드론 플랫폼에 적용 가능한 범용성을 확보하였다. EKF 기반 다중 센서 융합과 적응형 PID 제어를 통해 열기류 환경에서도 안정적 비행을 구현하여 감지-판단-대응의 통합 자율 화재 대응 솔루션을 제공 한다. 시스템의 운용상 제약사항으로는 풍속 15m/s 이상 강풍 환경에서의 안정성 제약, 연기로 인한 시야 제

한 시 감지 성능 75.2%로 저하, 14-16분의 제한적 비행시간이 있다. 또한 소화볼 2개의 제한적 페이로드 와 야간 및 악천후 조건에서의 운용 제약이 주요 한계점으로 작용한다. 본 시스템은 산불 초기 5분 이내 자율 대응을 통한 화재 피해 면적 70% 감소, 소방 인력의 안전 확

보, 관련 산업 기술 발전 촉진 및 4차 산업혁명 핵심 기술의 실용화 가속화가 기대된다. 특히 T-Motor AIR 2213/920KV 모터와 4S 8400mAh 배터리 구성으로 3kg 기체 중량에서도 안정적 호

버링과 정밀 제어가 가능하며, STM32H743VIH6의 480MHz 고속 처리와 BMI088/BMI270 IMU의 정밀 센 싱으로 열기류 환경에서도 우수한 자세 제어 성능을 달성하였다.

4. 결 론

본 연구에서는 산불 초기 대응의 골든타임을 놓치는 문제를 해결하기 위해 자율 화재 진압 드론 시스 템을 개발하였다. Jetson Orin Nano Super 기반 온디바이스 AI와 YOLOv8s를 활용한 실시간 화재 감지, Python Tkinter 관제센터를 통한 2차 승인 시스템, 듀얼 카메라 시스템을 통한 GPS 좌표 추정 및 정밀

정렬, MAVLink 프로토콜 기반 자율비행 제어를 통합하여 완전 자율 화재 대응 시스템을 구현하였다. STM32H743VIH6 FC와 BMI088/BMI270 IMU를 활용한 EKF 센서 융합과 적응형 PID 제어로 열기류

환경에서도 안정적 비행을 달성하였으며, 3D 프린터로 제작한 서보 기반 소화볼 투하기를 통해 정확한
화재 진압을 구현하였다. 실제 테스트 결과 화재 감지율 87.3%, YOLOv8s 추론 속도 45+ FPS, 투하 위치 정확도 1.0m, 관제센
터 통합 시스템 신뢰도 96.8%, 전체 응답시간 4분 32초의 우수한 성능을 달성하였다. 시스템의 주요 장점은 네트워크 독립적 온디바이스 AI 처리, Human-in-the-Loop 관제 시스템을 통한 | - 22 -

오탐지 최소화, 오픈소스 기반 모듈화 설계, 열기류 환경 대응 능력이며, 실제 화재 환경 검증 부족과 옵티컬 라이다 미탑재로 인한 고도 측정 오차가 한계점으로 남아있다. 본 시스템은 산불 초기 5분 이내 자율 대응으로 화재 피해 면적 70% 감소, 소방 인력 안전 확보, 4차

산업혁명 핵심 기술의 실용화에 기여할 것으로 기대된다. 참고문헌

(1) Fire Prevention News. (2024). "Forest Fire Response System Development Trends." Fire Prevention News, Available at: https://www.fpn119.co.kr/232256 [Accessed January 2025].
(2) Spider-i UAV Co., Ltd. (2024). "H300 Industrial Fire Fighting Drone Technical Specifications." Spider UAV Product Documentation, Seoul, Korea, Available at: https://spideruav.com/ko/제품/산업용-드론/h300-소방-드론/ [Accessed January 2025].
(3) Korea Fire Safety Institute. (2022). "Fire Suppression Technology Using Drones." KFSI Webzine, Vol. 12, December Issue, Available at: http://kfsi.or.kr/contents/webzine/202212/sub03-02.html [Accessed January 2025].
(4) Wikipedia Contributors. (2024). "Twisted Pair Cable Technology." Wikipedia, The Free Encyclopedia, Available at: https://en.wikipedia.org/wiki/Twisted_pair [Accessed January 2025].
(5) Toray Composite Materials America, Inc. (2023). "T300 Standard Modulus Carbon Fiber Technical Data
Sheet." | Toray | Technical | Documentation, | Tacoma, | WA, | USA, | pp. | 1-2, | Available | at: https://www.toraycma.com/wp-content/uploads/T300-Technical-Data-Sheet-1.pdf.
(6) SpeedyFPV. (2024). "600mm Carbon Fiber Hexacopter Frame Kit Specifications." SpeedyFPV Product
Catalog, | Available | at: | https://speedyfpv.com/products/600mm-carbon-fiber-hexacopter-drone-frame-kit-new
[Accessed January 2025].
(7) Zhou, L., Miller, J., Vezza, J., Mayster, M., Raffay, M., Justice, Q., Al Tamimi, Z., Hansotte, G., Sunkara, L. D., & Bernat, J. (2024). Additive Manufacturing: A Comprehensive Review. Sensors, 24(9), 2668. https://doi.org/10.3390/s24092668
(8) Ultralytics. (2024). "YOLOv8 Architecture and Performance Metrics." Ultralytics Documentation, Version 8.0, Available at: https://docs.ultralytics.com/ko/models/yolov8/#performance-metrics [Accessed January 2025].
(9) Lee, Y.H., & Kim, Y.S. (2020). "Comparison of CNN and YOLO for Object Detection." Journal of the Semiconductor & Display Technology, Vol. 19, No. 1, pp. 85-92, March 2020, Korea Semiconductor & Display Technology Society, Available at: https://koreascience.kr/article/JAKO202011161035249.pdf [Accessed January 2025].
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

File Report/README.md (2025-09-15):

# 최종보고서 Alpha Ver
### [Google Docs 공동 작업 스페이스](https://docs.google.com/document/d/106o5CShBEe7szLtclFux3OxCRUoWJ9Vq1TsLyF5sEMw/edit?usp=sharing)

# 중간보고서 Alpha Ver
### [Google Docs 공동 작업 스페이스](https://docs.google.com/document/d/1pVvOz4eLByB2WOTVAg2WT2LU4FtLWE3JpXoK3MW3RI8/edit?usp=sharing)

###### 부품 구매 리스트 추가하기

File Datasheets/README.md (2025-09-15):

# 드론 제작에 사용된 부품 & 재료 데이터시트

# 부품 구매 리스트 Alpha Ver
### [Google Docs 공동 작업 스페이스](https://docs.google.com/document/d/1nRSHEwY58dq7X9sT-Ti1DcgDuFTPXgdPE8P0EUMgVt0/edit?usp=sharing)

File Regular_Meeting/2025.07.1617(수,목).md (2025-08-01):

하드웨어팀 소화볼 투하기 모델링

소프트웨어팀 드론 모터 제어 코드 작성 1명, 객체인식 데이터셋 생성 및 정확도 보정 2명

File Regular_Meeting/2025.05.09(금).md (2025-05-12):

# 논의 내용
드론 자체 제작 or 기성품에 악세서리 추가 / 예산에 대한 이야기 05월 3주차에 결정 / 중간보고서 05월 30일까지 마감을 해놓고 피드백 마지막 3일 최종 

# 대회에 대해 궁금한 점 / 방향성 관련 문제
심사위원 전공자 & 비전공자 / 실현 가능성 있게 살을 덧붙여서 있어보이게 작성하기

# 확정된 사항
드론 자체 제작 고려중, 예산이 나온 후 결정

# 앞으로 진행할 내용
중간보고서 05월 30일까지 작성하고 매주마다 피드백, 방학 이후 마지막 3일 최종 마무리
하드웨어 제작은 중간보고서 이후에 진행

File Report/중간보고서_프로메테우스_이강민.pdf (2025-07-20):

# 대한기계학회 주최

# 제15회 전국학생설계경진대회(2025년)

# 설계 중간 보고서

참가부 | 고등부 ( ) / 대학부 ( V )
참가분야 | 공모주제 ( V ) / 자유주제 ( )
참가팀명 | 프로메테우스
설계제목 | 실시간 화재 탐지 시스템과 소화탄 투하 기능을 가진 스마트 소방 드론 시스템
지도교수/교사 | (소속) 경성대학교 (성명) 박장식 (연락처) 010-5503-6198
대표자 (신청인) | 성명 | 소속 | 연락처 (휴대폰) | E-mail | 주소
| 이강민 | 경성대학교 전자공학과 | 010-4928-2105 | qertiuy5377@na ver.com

# 참가팀원 인적사항

NO | 성명 | 소속 / 학년 | E-MAIL
1 | 이강민 | 경성대학교 전자공학과 / 4학년 | qertiuy5377@naver.com
2 | 송승진 | 경성대학교 전자공학과 / 4학년
3 | 권혁준 | 경성대학교 전자공학과 / 4학년
4 | 유찬영 | 경성대학교 메카트로닉스학과 / 4학년 | cksdud0515@naver.com
5 | 김철우 | 경성대학교 메카트로닉스학과 / 4학년

※ 중간보고서 제출 : 설계경진대회 홈페이지에서 보고서제출 클릭 ☞ 로그인한 후 신청번호 클릭

### ☞ 중간보고서 제출 (제출기한: 2025년 6월 2일(월) ~ 6월 27일(금))

※ 파일명 : 중간보고서_(참가팀명)_홍길동(대표자명)

### 1. 설계의 목적

최근 연속적으로 발생한 산불로 인해 산림이 파괴되고 인명피해까지 이어지는 상황에서, 피해를 최소화하기 위한 빠른 초기 대응의 중요성이 강조되고 있다. 그러나 산불 특성상 신속한 접근과 초기 진화의 어려움이 존재 한다. 본 프로젝트는 2025년 현재까지 진행되고 있는 러시아-우크라이나 전쟁에서 주요 전력으로 사용된 드론의 신

속한 기동성과 접근성에 주목하였다. 이러한 드론의 장점을 활용하여, 실시간 화재 탐지 시스템과 소화탄 투하 기능을 가진 '스마트 소방 드론 시스템' 구현을 목표하였다. 이를 통해 신속한 화재 탐지와 초기 진화가 가능해 짐으로써 산불 피해를 최소화할 수 있을 것으로 기대된다.

### 2. 설계 핵심 내용

### (1) 설계 문제의 정의

2025년 대한민국에서는 연속적으로 발생한 산불로 인해 약 104,788헥타르의 산림과 주거지가 파괴되며 역대 최대 규모의 피해를 기록하였다. 이는 서울시 면적의 약 1.7배에 달하는 수준으로, 32명의 인명 피해도 발생하 였다. 이러한 피해를 줄이기 위해서는 신속한 화재 탐지와 초기 진화가 매우 중요하다는 것을 인식하고, 대형 산불로 인한 추가 피해 예방을 목표로 설계를 구상하였다. 우선, 러시아-우크라이나 전쟁에서 드론의 활용성에 주목하였다. 전쟁에서 사용된 드론은 인명 피해를 남기는

폭탄을 투하하지만, 본 프로젝트는 생명을 지킬 수 있는 소화탄 투하를 구상하였다. 기존에도 다양한 기업에서 소화탄 또는 소방호스를 장착한 소방 드론이 개발되어 왔으나, 대부분 사람이 수동으로 조작해야 하는 한계가 있다. 따라서, 조종사의 개입 없는 실시간 딥러닝 기반 화재 탐지 시스템과 소화탄 투하 시스템을 활용하여 스마트

소방 드론을 구현하고자 한다. 이 구현을 통해 신속한 초기 대응이 가능한 미래형 화재 대응 플랫폼을 기대할 수 있다.

### (2) 설계 방법 및 제약조건

고온 환경에서의 드론 비행은 일반 환경보다 높은 출력 성능을 요구한다. 이를 위해 헥사콥터(6축)와 옥토콥 터(8축) 구조가 검토되었으나, 초기 설계에서 정한 중량 제한(3kg)과 높은 제작 비용을 고려하여 헥사콥터 구조 로 결정하였다. 헥사콥터는 기존 쿼드콥터 대비 추력 향상 및 자세 제어 정밀도를 높일 수 있으며, 비행 중 일 부 모터 또는 프로펠러에 장애가 발생하더라도 일정 수준 이상의 비행 지속성을 유지할 수 있는 장애 허용성 (fault tolerance)을 제공한다. 소화탄 투하 시 발생하는 드론의 무게중심 급변을 최소화하기 위해 중력 낙하형 투하 방식을 적용할 예정이

다. 또한 Jetson Orin Nano Super를 이용하여 실시간 화재 탐지를 수행하고, 비행 컨트롤러(Flight Controller)를 활용하여 센서 측정값의 피크치 오버플로우를 방지하며, 소화탄을 잡는 그랩 모듈 작동 시 발생하는 모터 부하 변동을 실시간으로 감지하여 기체의 순간적인 흔들림과 상승을 보정하는 알고리즘을 설계에 반영할 예정이다. 장시간 고온 환경에 노출 시 드론 내부의 온도 민감형 센서 측정값의 신뢰도가 저하되거나 고장날 가능성이

있다. 이를 최소화하기 위해 방열판 및 열반사필름을 활용한 열 차단 설계를 적용할 예정이다. 또한 인공지능의 오작동으로 인한 인명피해를 방지하기 위해 모니터링이 가능한 관제 시스템에서의 이중 승인 절차를 통해 소화 탄 투하를 할 수 있도록 소프트웨어를 추가하여 해결할 것이다. 공학적인 문제점뿐만 아니라 법적인 문제도 존재하는데, 항공안전법 제206조와 제310조에 따르면 3kg을 초과

하는 투하물을 장착한 기체는 사전 허가와 안정성 심사가 필수이다. 따라서 제한적인 환경에서 구현하기 위해

카본 프레임과 모터, 소화탄 모형을 사용하여 중량을 3kg 이하로 제한하였다.

### 3. 현재까지의 성과 및 문제점 해결방안

일반적인 소방 드론은 약 25kg 이상의 페이로드를 요구하나, 법적인 제한으로 인해 중량을 3kg 이하로 제한 해야 했다. 제한적인 환경에서 구현하기 위해 부품의 공식 제원을 확인하여 정확한 수치를 바탕으로 구체화하고 현재까지 소프트웨어 측면에서 드론 동작의 전체적인 파이프라인과 플로우차트를 디자인하였다. [ YOLOv8 네트워크 아키텍처의 세부적인 블록 다이어그램 (Detailed of YOLOv8 Network's Architecture) ]

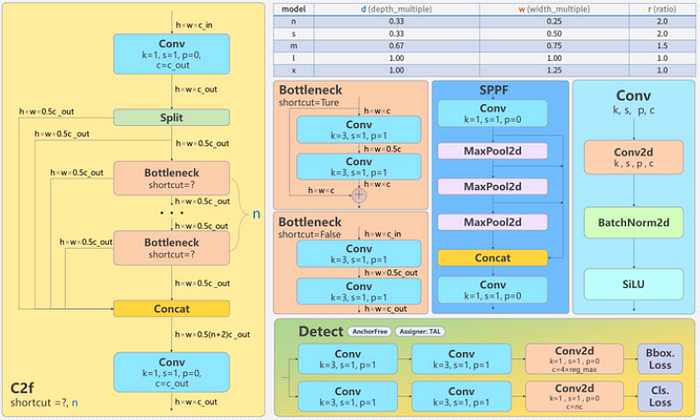
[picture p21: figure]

본 프로젝트는 화재 탐지라는 목표를 가지고 있어 실시간 인식 시스템이 요구된다. 그리고 실시간 인식 시스템 은 응답성과 안정성이 매우 중요하다. 그러나 모든 연산을 하나의 보드로 처리할 경우 부하가 증가하여 지연 문 제가 발생할 가능성이 있다. 본 프로젝트에서는 객체 인식용 Jetson 보드와 드론 제어용 비행 컨트롤러(Flight Controller) 부분으로 나누어 두 개의 보드를 사용할 예정이다. 화재 탐지 시스템은 딥러닝 기반 객체 인식 기술이 핵심이며, 드론 플랫폼의 제약 조건을 고려할 때 실시간

연산 능력 확보가 매우 중요하다. 이를 위해 고성능 GPU와 딥러닝 추론 최적화 엔진(TensorRT)을 지원하는 Jetson Orin Nano Super 보드를 채택하였다. 이 보드는 YOLOv8s과 같은 경량 딥러닝 모델을 TensorRT 기반으 로 실시간 처리할 수 있는 연산 성능(8.7 Tops)을 제공하며, 공식 데이터 기준 640 Pixel 입력 시 약 1.2ms의 빠 른 추론 속도를 지원한다. 또한, CUDA 기반의 병렬 처리가 가능하고, ROS 환경과의 호환성도 우수하여 센서, 카메라와의 통합 및 실시간 응답성 구현에 유리하다. 이러한 이유로 Jetson Orin Nano Super는 본 프로젝트의

실시간 객체 인식 성능과 드론 탑재 조건을 모두 만족하는 최적의 보드로 판단되어 선정하였다. YOLOv8s의 객체인식 정확도는 90.4% ~ 99.6% 수준이다. 하지만, 화재 현장과 같은 민감한 환경에서는 100% 가 아니라면 소화탄 투하 시에 인명 피해가 있을 수 있다. 민감한 환경에서는 추가적인 안전 장치가 필요하므로 모니터링 후 사람의 최종 승인이 있어야만 소화탄을 투하하도록 절차를 강화할 예정이다.
드론 플랫폼에서 화재 탐지와 초기 소화를 위한 소화탄 투하 기능을 구현하기 위해 고출력 드론용 모터가 필 요하다. 그러나 고출력 모터의 높은 가격과 제한된 예산으로 인해 적합한 부품 확보에 어려움이 있었다. 이에 따라 드론의 중량 제한과 법적 조건 등 현실적 제약을 고려하여 설계 방향을 최적화하였다. 이러한 예산상의 제 약으로 기존 보유 모터를 활용하여 비용 부담을 줄이기로 하였다. 드론의 종류는 모터의 수에 따라 크게 쿼드콥터, 헥사콥터, 옥토콥터로 나뉜다. 각각의 종류들은 고유한 장단

점을 가지고 있다. 본 프로젝트의 구상 단계에서 높은 보급률과 접근성을 보유한 쿼드콥터를 고려하였으나, 쿼

드콥터의 낮은 안정성과 최대이륙중량이 화두되었다. 또한, 옥토콥터는 가격이 높고 큰 프레임이 대부분이어서 3kg을 초과할 우려가 있어 프로젝트의 방향성과 맞지 않았다. 따라서, 헥사콥터를 선정함으로써 균형을 맞추었 다. 드론의 부자재 제작을 위한 3D 프린팅 방식은 FDA 출력 방식을 사용함으로써 높은 설계 자유도를 확보하고 저

렴한 가공 비용을 기대할 수 있다. 또한, PLA 필라멘트를 사용하여 높은 접근성과 쉬운 가공을 기대할 수 있다. 그러나 소방 드론은 화재 현장의 고온 환경에 노출된다. 따라서 PLA 필라멘트의 낮은 열 내구성은 화재 현장과

같은 고온 환경에서 부적합하다. 이를 해결하기 위해 ABS, PC 필라멘트 등 다양한 소재를 고려할 예정이며, 필 요 시 교체할 예정이다.

### 4. 향후 설계 진행 계획

중간보고서 작성 단계에서 확정한 중량 및 성능 조건에 최적화된 부품들의 선정을 완료하고 구매하였다. 최종 보고서 작성 시점까지 실제 부품의 미세한 성능 오차를 보정 하기 위해 공식 제원을 바탕으로 각 부품의 오프 셋(offset)을 설정할 예정이다. 이를 기반으로 하드웨어 조립과 최종 시스템 통합을 진행하며, 소프트웨어 측면에 서는 수집된 데이터셋을 활용하여 TensorRT 기반의 YOLOv8s 모델을 추가적으로 학습 및 최적화하여 객체 인식 정확도를 향상할 계획이다. 또한, 드론의 열 노출에 따른 안전성을 확보하기 위해 자동 이탈 알고리즘과 온도 감지 기반의 회피 시스템을

구현하고, 통합 실험 및 평가를 통해 설계 목표의 달성 여부를 명확히 검증할 예정이다. 더불어, 앤시스(Ansys)
를 활용한 유한요소해석(FEA)을 수행하여 설계의 타당성과 구조적 안정성을 종합적으로 검증할 계획이다. 설계 진행 내용 | 4월 | 5월 | 6월 | 7월 | 8월 | 9월

주제 선정

개념 설계

상세 설계

프로토타입 제작

통합 테스트 및 보고서 작성

주제 선정 : 4월 7일 ~ 5월 2일
개념 설계 : 5월 2일 ~ 6월 27일
상세 설계 : 6월 27일 ~ 7월 18일
프로토타입 제작 : 7월 11일 ~ 8월 25일
동작 테스트 및 보고서 작성 : 8월 25일 ~ 9월 12일

### 5. 참고문헌

웹사이트
- https://github.com/ultralytics/ultralytics
- https://blog.roboflow.com/what-is-yolov8

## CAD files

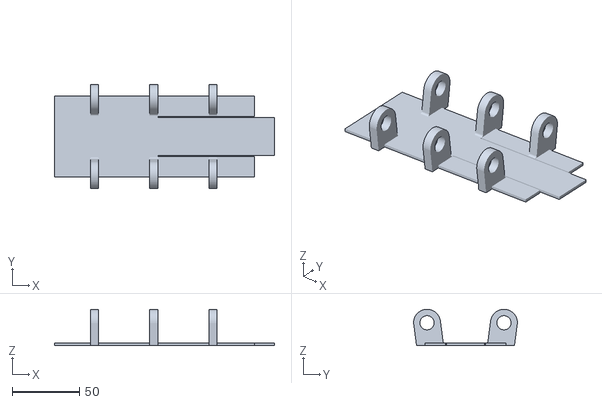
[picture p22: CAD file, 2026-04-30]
stl/Drone/Drone_BAT_House_Upper.stl
163.0 x 77.0 x 27.0

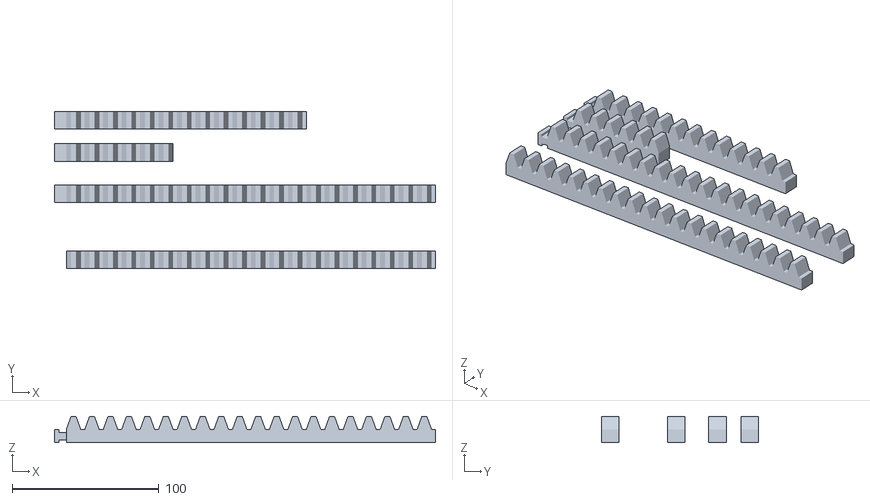
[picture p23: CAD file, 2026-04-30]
stl/Station/Station_Rack.stl
259.3 x 107.0 x 18.0

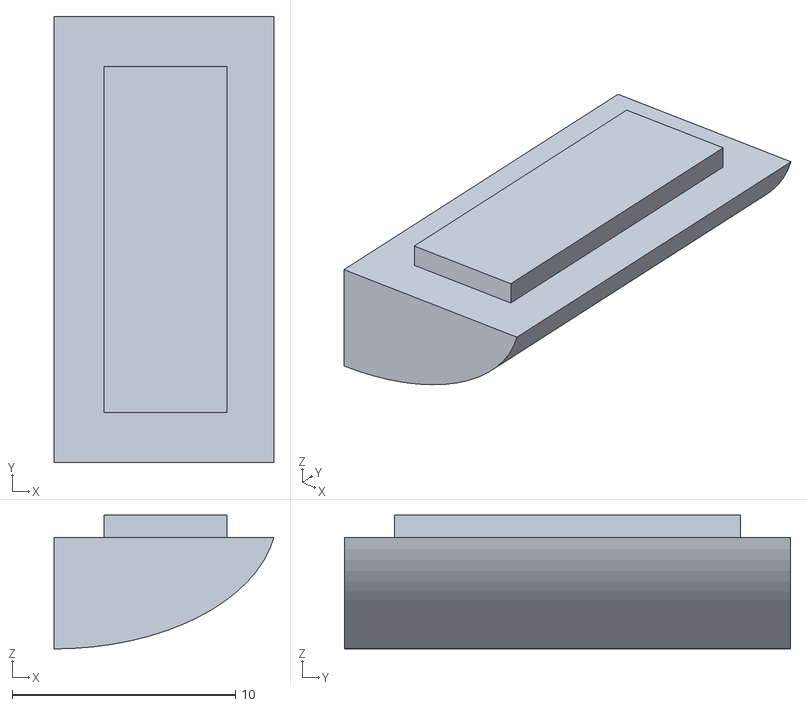
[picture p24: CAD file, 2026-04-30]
stl/Drone/Drone_BAT_House_Hook.stl
9.86 x 20.0 x 6.00

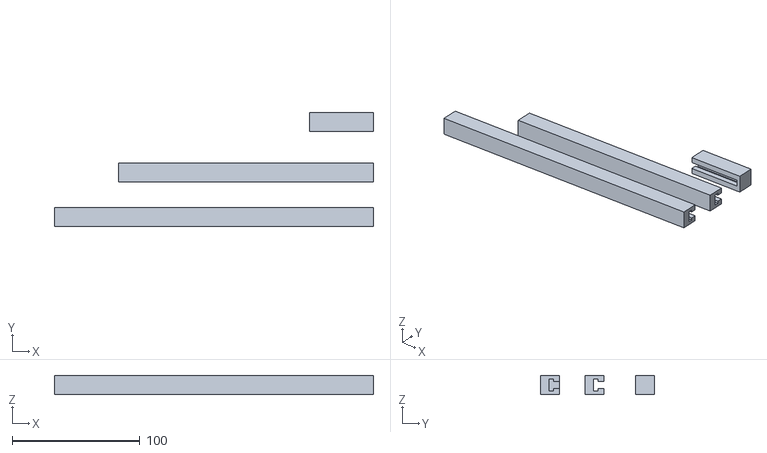
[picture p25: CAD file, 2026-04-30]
stl/Station/Station_Bar.stl
250.0 x 89.5 x 15.0

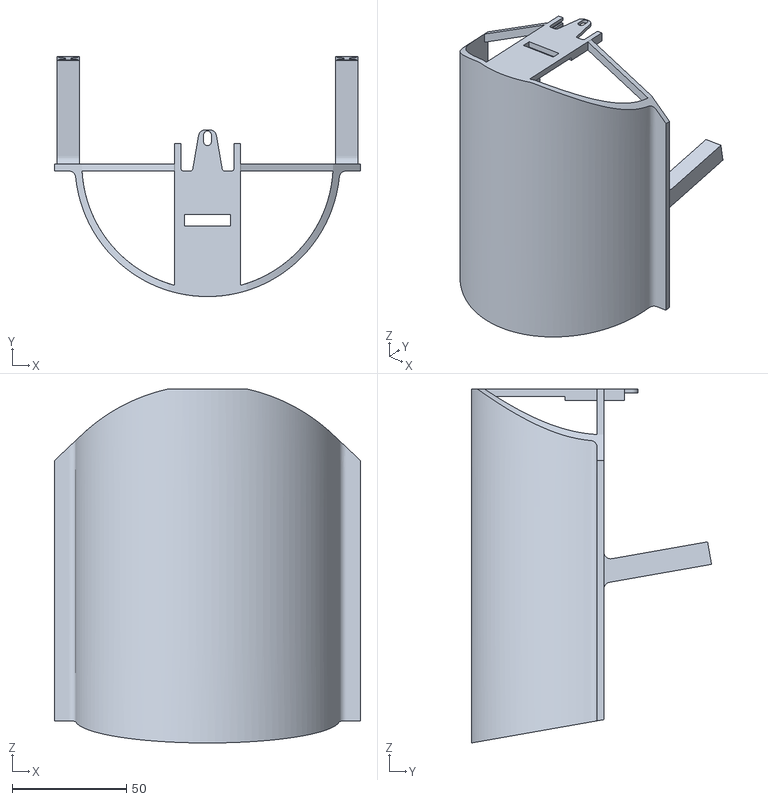
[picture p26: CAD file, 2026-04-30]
stl/Drone/Drone_Bomb_Plate.stl
134.0 x 105.2 x 155.0

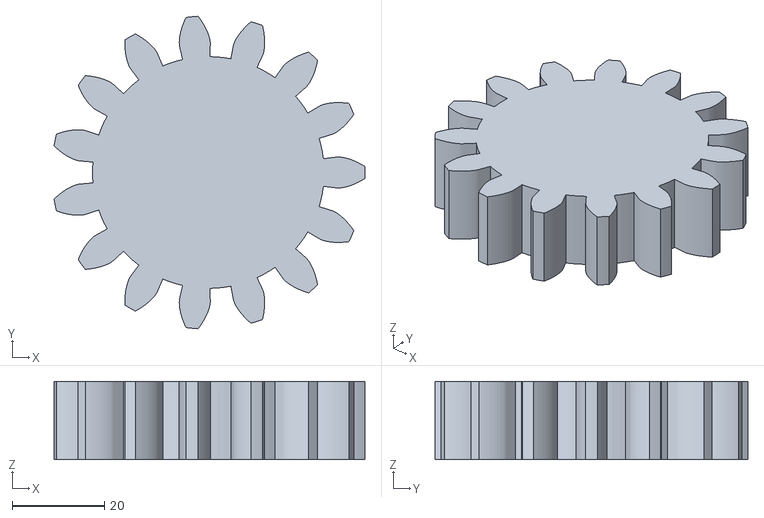
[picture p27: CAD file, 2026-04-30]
stl/Station/Station_Pinion.stl
67.5 x 67.9 x 17.0

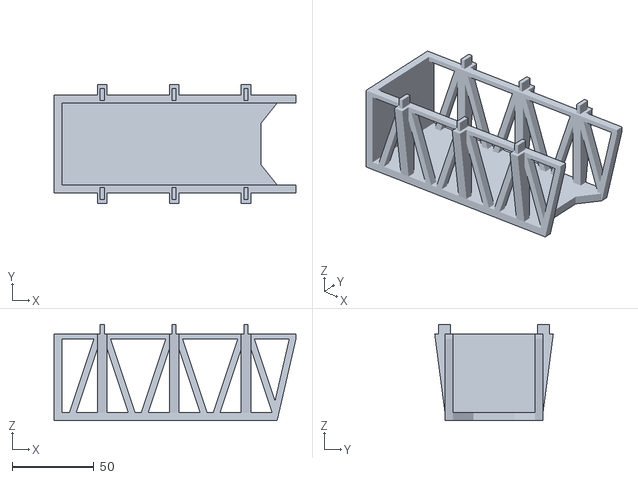
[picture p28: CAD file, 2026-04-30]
stl/Drone/Drone_BAT_House_Lower.stl
148.0 x 72.6 x 59.0

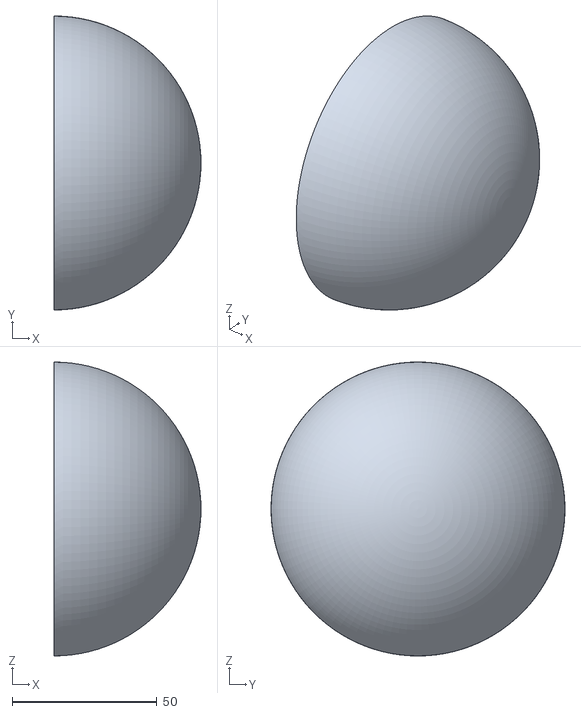
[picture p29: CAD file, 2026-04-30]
stl/Drone/Drone_4inch_Ball.stl
50.8 x 101.6 x 101.6

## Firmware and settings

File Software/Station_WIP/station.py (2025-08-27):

import time
import board
import busio
import RPi.GPIO as GPIO
import adafruit_vl53l0x
from Doc_match import Docking

# 통신 클라이언트 라이브러리 임포트
from rpi_client import RPiClient
import queue

class DroneStation:
    """
    드론 스테이션의 도킹 및 장전 과정을 제어하는 클래스.
    카메라, ToF 센서, 서보 모터, PC와의 통신을 통합 관리합니다.
    """

    def __init__(self, pc_host):
        # --- 1. 하드웨어 설정 ---
        GPIO.setmode(GPIO.BCM)
        self.SERVO_FB_PIN = 17      # 전, 후진 서보
        self.SERVO_LR_PIN = 18      # 좌, 우 서보
        self.SERVO_AMMO_PIN = 27    # 발 수 구분 서보

        self.XSHUT_PINS = [22, 23, 24, 25]  # ToF 핀번호(4개)
        self.PWM_FREQUENCY = 50     # PWM 신호 주파수(50Hz)

        GPIO.setup(self.SERVO_FB_PIN, GPIO.OUT)
        GPIO.setup(self.SERVO_LR_PIN, GPIO.OUT)
        GPIO.setup(self.SERVO_AMMO_PIN, GPIO.OUT)

        self.pwm_fb = GPIO.PWM(self.SERVO_FB_PIN, self.PWM_FREQUENCY)
        self.pwm_lr = GPIO.PWM(self.SERVO_LR_PIN, self.PWM_FREQUENCY)
        self.pwm_ammo = GPIO.PWM(self.SERVO_AMMO_PIN, self.PWM_FREQUENCY)
        
        self.pwm_fb.start(0)
        self.pwm_lr.start(0)
        self.pwm_ammo.start(0)

        # --- 2. 변수 및 상수 ---
        self.TOLERANCE_MM_TOF = 5
        self.TARGET_DISTANCE_MM_TOF = 100
        self.TOLERANCE_PX_CAMERA = 5
        self.TARGET_Y_RELATIVE_PX = -100

        self.SERVO_360_STOP = 7.5
        self.SERVO_360_FORWARD = 8.5
        self.SERVO_360_BACKWARD = 6.5
        self.SERVO_360_LEFT = 8.5
        self.SERVO_360_RIGHT = 6.5
        self.AMMO_LOAD_SPEED = 8.5

        # --- 3. 통신 클라이언트 초기화 ---
        self.pc_host = pc_host
        self.client = RPiClient(host=self.pc_host)

    def setup_tof_sensors(self):
        """ToF 센서 순차 활성화 및 I2C 주소 재할당"""
        i2c_bus = busio.I2C(board.SCL, board.SDA)
        for pin in self.XSHUT_PINS:
            GPIO.setup(pin, GPIO.OUT)
            GPIO.output(pin, GPIO.LOW)
        time.sleep(0.1)
        
        sensors = []
        for i, xshut_pin in enumerate(self.XSHUT_PINS):
            GPIO.output(xshut_pin, GPIO.HIGH)
            time.sleep(0.1)
            
            try:
                tof = adafruit_vl53l0x.VL53L0X(i2c_bus)
                new_address = 0x29 + i
                tof.set_address(new_address)
                sensors.append(adafruit_vl53l0x.VL53L0X(i2c_bus, address=new_address))
                print(f"✅ 센서 {i+1}에 주소 0x{new_address:x} 할당 완료.")
            except ValueError:
                print(f"⚠️ 센서 {i+1}를 찾을 수 없거나 주소 설정에 실패했습니다. 연결을 확인하세요.")
        return sensors

    def get_sensor_data(self, sensors):
        """모든 ToF 센서에서 현재 거리 측정"""
        distances = []
        try:
            for tof in sensors:
                distances.append(tof.range)
            return distances
        except Exception as e:
            print(f"센서 읽기 오류: {e}")
            return [None] * len(sensors)

    def control_servos_tof(self, offset_fb, offset_lr):
        """ToF 센서 측정 오차 기반 서보 제어"""
        if abs(offset_fb) > self.TOLERANCE_MM_TOF:
            self.pwm_fb.ChangeDutyCycle(self.SERVO_360_BACKWARD if offset_fb > 0 else self.SERVO_360_FORWARD)
            print(f"  -> ToF: {'뒤로' if offset_fb > 0 else '앞으로'} 이동")
        else:
            self.pwm_fb.ChangeDutyCycle(self.SERVO_360_STOP)
            print("  -> ToF: 앞뒤 정렬 완료")
            
        if abs(offset_lr) > self.TOLERANCE_MM_TOF:
            self.pwm_lr.ChangeDutyCycle(self.SERVO_360_LEFT if offset_lr > 0 else self.SERVO_360_RIGHT)
            print(f"  -> ToF: {'왼쪽' if offset_lr > 0 else '오른쪽'}으로 이동")
        else:
            self.pwm_lr.ChangeDutyCycle(self.SERVO_360_STOP)
            print("  -> ToF: 좌우 정렬 완료")
        time.sleep(0.1)

    def load_ammo(self, count):
        """장전 서보 구동"""
        print(f"\n🚀 {count}발의 소화탄을 장전합니다.")
        for i in range(count):
            print(f"  -> 장전 중... {i+1} / {count}")
            self.pwm_ammo.ChangeDutyCycle(self.AMMO_LOAD_SPEED)
            time.sleep(1.0)
            self.pwm_ammo.ChangeDutyCycle(self.SERVO_360_STOP)
            time.sleep(0.5)
        print("✅ 장전 완료!")

    def run_station_process(self, ammo_count):
        """카메라와 ToF 센서를 사용하여 도킹 및 장전 과정을 실행하는 함수"""
        try:
            docking = Docking()

            # --- 1단계: 카메라를 이용한 좌우 정렬 및 전진 ---
            print("\n📷 카메라를 사용하여 시각적 정렬을 시작합니다.")
            
            while True:
                dot_x_relative, dot_y_relative, found = docking.get_coordinates()
                
                if not found:
                    print("⚠️ 빨간 마커를 찾을 수 없습니다. 전진을 계속합니다.")
                    self.pwm_fb.ChangeDutyCycle(self.SERVO_360_FORWARD)
                    self.pwm_lr.ChangeDutyCycle(self.SERVO_360_STOP)
                    time.sleep(0.5)
                    continue

                if abs(dot_x_relative) > self.TOLERANCE_PX_CAMERA:
                    self.pwm_lr.ChangeDutyCycle(self.SERVO_360_LEFT if dot_x_relative > 0 else self.SERVO_360_RIGHT)
                    print(f"  -> 카메라: {'왼쪽' if dot_x_relative > 0 else '오른쪽'}으로 이동")
                else:
                    self.pwm_lr.ChangeDutyCycle(self.SERVO_360_STOP)
                    print("  -> 카메라: 좌우 정렬 완료")

                if dot_y_relative > self.TARGET_Y_RELATIVE_PX:
                    self.pwm_fb.ChangeDutyCycle(self.SERVO_360_FORWARD)
                    print("  -> 카메라: 앞으로 이동")
                else:
                    print("✅ 카메라 정렬 및 거리 확보 완료. ToF 센서 단계로 넘어갑니다.")
                    self.pwm_fb.ChangeDutyCycle(self.SERVO_360_STOP)
                    self.pwm_lr.ChangeDutyCycle(self.SERVO_360_STOP)
                    break
                time.sleep(0.1)

            docking.cleanup()

            # --- 2단계: ToF 센서를 이용한 정밀 매칭 및 장전 ---
            print("\n⚙️ ToF 센서로 정밀 매칭을 시작합니다.")
            tof_sensors = self.setup_tof_sensors()
            
            if len(tof_sensors) < 4:
                print("🚨 4개의 ToF 센서가 모두 연결되지 않았습니다. 장전을 시작할 수 없습니다.")
                return False
            else:
                print(f"-> 소화탄 장전 발수: {ammo_count} 발")
                
                while True:
                    distances = self.get_sensor_data(tof_sensors)
                    
                    if None in distances:
                        print("⚠️ 센서 데이터를 읽을 수 없습니다. 다시 시도합니다.")
                        time.sleep(1)
                        continue
                        
                    is_all_matched = (
                        abs(distances[0] - self.TARGET_DISTANCE_MM_TOF) <= self.TOLERANCE_MM_TOF and
                        abs(distances[1] - self.TARGET_DISTANCE_MM_TOF) <= self.TOLERANCE_MM_TOF and
                        abs(distances[2] - self.TARGET_DISTANCE_MM_TOF) <= self.TOLERANCE_MM_TOF and
                        abs(distances[3] - self.TARGET_DISTANCE_MM_TOF) <= self.TOLERANCE_MM_TOF
                    )
                    
                    if is_all_matched:
                        print("\n✅ 드론의 소화탄 장착부가 완벽하게 매칭되었습니다.")
                        self.pwm_fb.ChangeDutyCycle(self.SERVO_360_STOP)
                        self.pwm_lr.ChangeDutyCycle(self.SERVO_360_STOP)
                        self.load_ammo(ammo_count)
                        return True
                    else:
                        offset_fb = distances[0] - distances[2]
                        offset_lr = distances[1] - distances[3]
                        print(f"    -> 정렬 필요: 앞뒤 오차={offset_fb:.2f}mm, 좌우 오차={offset_lr:.2f}mm")
                        self.control_servos_tof(offset_fb, offset_lr)
                        
                    time.sleep(0.1)
                        
        except KeyboardInterrupt:
            print("\n\n👋 사용자 중지 요청.")
            return False
        except Exception as e:
            print(f"\n\n🚨 오류 발생: {e}")
            return False

    def process_command(self, command):
        """PC로부터 받은 명령을 처리하고 결과를 반환합니다."""
        if command.get('command') == 'start_docking':
            ammo_count = command.get('ammo_count')
            print(f"\n\n[명령 처리] '도킹 시작' 명령 수신. 장전 수: {ammo_count} 발")
            
            success = self.run_station_process(ammo_count)
            
            if success:
                return {'status': 'success', 'message': f'{ammo_count}발 장전 완료'}
            else:
                return {'status': 'failure', 'message': '도킹 및 장전 실패'}
        
        return {'status': 'error', 'message': '알 수 없는 명령'}

    def cleanup(self):
        """프로그램 종료 시 자원 정리"""
        self.pwm_fb.stop()
        self.pwm_lr.stop()
        self.pwm_ammo.stop()
        GPIO.cleanup()
        self.client.close()

    def run(self):
        """메인 실행 루프"""
        print("--- 드론 스테이션 프로그램 시작 ---")
        try:
            while True:
                if not self.client.is_connected:
                    print("서버에 재연결을 시도합니다...")
                    if self.client.connect():
                        print(">> PC로부터 명령을 기다립니다...")
                    else:
                        time.sleep(5)
                        continue

                try:
                    command = self.client.command_queue.get(timeout=1)
                    result = self.process_command(command)
                    self.client.send_response(result)
                except queue.Empty:
                    pass

        except KeyboardInterrupt:
            print("\n\n👋 사용자에 의해 프로그램이 중지됩니다.")
        finally:
            self.cleanup()
            print(">> 프로그램 종료.")


# --- 4. 메인 프로그램 진입점 ---
if __name__ == '__main__':
    # PC의 실제 로컬 이름 또는 IP 주소로 변경해주세요!
    PC_HOSTNAME = 'Your-PC-Name.local'
    station = DroneStation(pc_host=PC_HOSTNAME)
    station.run()

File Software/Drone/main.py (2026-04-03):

# Jetson Orin Nano (드론)용 최종 코드
import socket
import threading
import time
import json
import os
import cv2

# 사용자가 만든 모듈
from DroneCommunicator import DroneCommunicator
from patrol import Patrol
from Fire_detector import Fire_detector
from drone_controller import DroneController
from Fire_extinguishing import Fire_extinguishing
from pipeline import gstreamer_pipeline
from Landing import Landing
from servo_control import Servo

# --- 드론 시스템 객체 생성 ---
drone_system = DroneController()

# --- 서보 객체 생성 ---
servo = Servo(servo_pin=33)

# --- 통신 모듈 객체 생성 ---
CONTROLLER_PC_HOSTNAME = 'AERO_17.local'
communicator = DroneCommunicator(pc_hostname=CONTROLLER_PC_HOSTNAME)

# --- 카메라 객체 생성 ----
pipeline0 = gstreamer_pipeline(sensor_id=0)
pipeline1 = gstreamer_pipeline(sensor_id=1)
cap0 = cv2.VideoCapture(pipeline0, cv2.CAP_GSTREAMER)
cap1 = cv2.VideoCapture(pipeline1, cv2.CAP_GSTREAMER)

# --- 화재탐지 객체 생성 ---
fire_detector = Fire_detector(cap0, cap1)

# --- 착륙 시스템 객체 생성 ---
landing = Landing(cap1, drone_system)

# --- 순찰 객체 생성 ---
patrol = Patrol(drone_system, fire_detector, landing, communicator)

# --- 소화볼 투하 객체 생성 ---
fire_extinguishing = Fire_extinguishing(drone_system, fire_detector, landing, communicator, servo)

# --- 메인 로직: 화재 탐지 및 소화 시스템 ---
def main():
    active_threads = []

    try:
        print("[메인] 화재 탐지 및 소화 시스템 시작")
        print("[메인] 화재 탐지: 활성화")
        print("[메인] 화재 진압: 활성화")

        # 드론 연결
        if not drone_system.connect():
            print("[메인] 드론 연결 실패")
            return

        if not cap0.isOpened() or not cap1.isOpened():
            print("[메인] 카메라 초기화 실패")
            return

        communicator.start_receiver()
        print("[메인] 명령 수신 대기 중...")

        while True:
            try:
                data = communicator.receive_data()
                if data:
                    try:
                        command_data = json.loads(data.decode('utf-8').strip())

                        # [최적화] 완료된 스레드를 리스트에서 제거 (리스트 컴프리헨션으로 한 줄 처리)
                        active_threads = [t for t in active_threads if t.is_alive()]
                        if len(active_threads) > 0:
                            print(f"[메인] 현재 {len(active_threads)}개 미션 진행 중 - 새 명령 거부")
                            communicator.send_status_update("MISSION_IN_PROGRESS", None)
                            continue

                        # 화재 진압 명령 처리
                        if isinstance(command_data, dict) and command_data.get('type') == 'EXTINGUISH':
                            target = command_data.get('target')
                            if target and 'lat' in target and 'lon' in target:
                                print(f"[메인] 화재 진압 명령 수신: 위도 {target['lat']:.7f}, 경도 {target['lon']:.7f}")

                                communicator.send_status_update("EXTINGUISH_START", None)

                                mission_thread = threading.Thread(
                                    target=fire_extinguishing.run,
                                    args=(target,),
                                    daemon=True,
                                    name="ExtinguishMission"
                                )
                                mission_thread.start()
                                active_threads.append(mission_thread)
                            else:
                                print("[메인] 잘못된 화재 진압 목표 좌표")

                        # 순찰 명령 처리
                        elif isinstance(command_data, list):
                            if len(command_data) > 0:
                                print(f"[메인] 순찰 경로 수신: {len(command_data)}개 지점")

                                communicator.send_status_update("PATROL_START", None)

                                mission_thread = threading.Thread(
                                    target=patrol.run,
                                    args=(command_data,),
                                    daemon=True,
                                    name="PatrolMission"
                                )
                                mission_thread.start()
                                active_threads.append(mission_thread)
                            else:
                                print("[메인] 빈 순찰 경로")

                        else:
                            print(f"[메인] 알 수 없는 명령: {command_data}")

                    except json.JSONDecodeError as e:
                        print(f"[메인] JSON 파싱 오류: {e}")
                    except Exception as e:
                        print(f"[메인] 명령 처리 오류: {e}")

                time.sleep(0.1)

            # [최적화] socket.timeout 제거 — receive_data()는 DroneCommunicator 내부에서
            # accept() 블로킹으로 동작하므로, 여기서 socket.timeout은 발생하지 않음.
            # 불필요한 예외 핸들러를 제거하여 코드 명확성 향상.
            except Exception as e:
                print(f"[메인] 수신 오류: {e}")
                time.sleep(1)

    except KeyboardInterrupt:
        print("\n[메인] 프로그램 종료 중...")

        print("[메인] 진행중인 미션 중단...")
        for thread in active_threads:
            if thread.is_alive():
                print(f"[메인] {thread.name} 종료 대기...")
                thread.join(timeout=2)

        if drone_system.is_armed:
            print("[메인] 긴급 착륙...")
            try:
                drone_system.set_mode_land()
                time.sleep(5)
                drone_system.disarm()
            # [최적화] bare except → except Exception
            # 기존: except: (SystemExit, KeyboardInterrupt 등 시스템 예외까지 무시)
            # 수정: except Exception (일반 예외만 포착, 시스템 예외는 전파)
            except Exception:
                print("[메인] 긴급 착륙 실패")

    except Exception as e:
        print(f"[메인] 치명적 오류: {e}")

    finally:
        # 리소스 정리
        print("[메인] 리소스 정리 중...")

        # [최적화] bare except → except Exception (3개소 동일 적용)
        # bare except는 KeyboardInterrupt, SystemExit 등도 삼키므로,
        # 종료 과정에서 Ctrl+C 재입력 시 프로세스가 멈출 수 있음.
        try:
            servo.cleanup()
        except Exception:
            pass

        try:
            cap0.release()
            cap1.release()
            cv2.destroyAllWindows()
        except Exception:
            pass

        print("[메인] 종료 완료")

if __name__ == '__main__':
    main()

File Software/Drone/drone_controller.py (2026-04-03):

from pymavlink import mavutil
import time
import math

# [최적화] 비행 모드 상수 정의
# 기존: 매직 넘버(4, 6, 9, 17)를 직접 사용하여 의미 파악 어려움
# 수정: 이름 있는 상수로 추출하여 가독성 및 유지보수성 향상
FLIGHT_MODE_GUIDED = 4
FLIGHT_MODE_RTL = 6
FLIGHT_MODE_LAND = 9
FLIGHT_MODE_BRAKE = 17

class DroneController:
    def __init__(self, connection_string='/dev/ttyACM0', baudrate=115200):
        self.connection_string = connection_string
        self.baudrate = baudrate
        self.master = None
        self.is_armed = False

        # 고도 정보
        self.set_alt = 2.0        # 설정 고도 (이륙, 주행 중 유지할 고도)
        self.archived_alt = None  # 이륙 완료 판정 고도 (set_alt의 95%)

        # GPS 정보
        self.home_lat = None
        self.home_lon = None

    def connect(self):
        """FC 연결"""
        try:
            print("[드론] FC 연결 중...")
            self.master = mavutil.mavlink_connection(
                self.connection_string,
                baud=self.baudrate
            )
            self.master.wait_heartbeat()
            print("[드론] FC 연결 성공")

            # 데이터 스트림 요청
            self.master.mav.request_data_stream_send(
                self.master.target_system,
                self.master.target_component,
                mavutil.mavlink.MAV_DATA_STREAM_ALL,
                50,
                1
            )

            # 홈 GPS 좌표 저장
            print("[드론] 홈 GPS 좌표 읽는 중...")
            for i in range(10):
                msg = self.master.recv_match(type='GLOBAL_POSITION_INT', blocking=True, timeout=1)
                if msg:
                    self.home_lat = msg.lat / 1e7
                    self.home_lon = msg.lon / 1e7
                    print(f"[드론] 홈 위치 저장: 위도 {self.home_lat:.7f}, 경도 {self.home_lon:.7f}")
                    return True

            print("[드론] 홈 GPS 좌표 읽기 실패")
            return False

        except Exception as e:
            print(f"[드론] 연결 실패: {e}")
            return False

    def _set_mode(self, mode_id):
        """[최적화] 비행 모드 전환 공통 메서드 추출
        기존: set_mode_guided/rtl/land/brake 각각에 동일한 MAVLink 전송 코드 중복
        수정: 공통 로직을 하나의 메서드로 통합하여 코드 중복 제거 (DRY 원칙)
        """
        self.master.mav.set_mode_send(
            self.master.target_system,
            mavutil.mavlink.MAV_MODE_FLAG_CUSTOM_MODE_ENABLED,
            mode_id
        )
        time.sleep(0.1)

    def set_mode_guided(self):
        """GUIDED 모드 설정"""
        self._set_mode(FLIGHT_MODE_GUIDED)

    def set_mode_rtl(self):
        """RTL(Return To Launch) 모드 설정"""
        self._set_mode(FLIGHT_MODE_RTL)

    def set_mode_land(self):
        """LAND 모드 설정"""
        self._set_mode(FLIGHT_MODE_LAND)

    def set_mode_brake(self):
        """BRAKE 모드 설정"""
        self._set_mode(FLIGHT_MODE_BRAKE)

    def arm(self):
        """시동"""

        # GUIDED 모드 설정
        self.set_mode_guided()

        # 시동 전 홈 위치 리셋 (중요!)
        self.master.mav.command_long_send(
            self.master.target_system,
            self.master.target_component,
            mavutil.mavlink.MAV_CMD_DO_SET_HOME,
            0, 1, 0, 0, 0, 0, 0, 0  # 현재 위치를 홈으로 설정
        )
        time.sleep(0.5)

        # ARM 명령
        self.master.mav.command_long_send(
            self.master.target_system,
            self.master.target_component,
            mavutil.mavlink.MAV_CMD_COMPONENT_ARM_DISARM,
            0, 1, 0, 0, 0, 0, 0, 0
        )
        time.sleep(0.1)
        print("\n[드론] 시동 중...")

        # 시동 확인
        for i in range(10):
            msg = self.master.recv_match(type='HEARTBEAT', blocking=True, timeout=5)
            if msg and msg.get_srcSystem() == 1 and msg.get_srcComponent() == 1:
                self.is_armed = msg.base_mode & mavutil.mavlink.MAV_MODE_FLAG_SAFETY_ARMED
                if self.is_armed:
                    print("[드론] 시동 성공")
                    return True
            time.sleep(0.1)
        print("[드론] 시동 실패")
        return False

    def disarm(self):
        """시동 끄기"""
        print("\n[드론] 시동 끄기...")

        self.master.mav.command_long_send(
            self.master.target_system,
            self.master.target_component,
            mavutil.mavlink.MAV_CMD_COMPONENT_ARM_DISARM,
            0, 0, 0, 0, 0, 0, 0, 0
        )
        time.sleep(0.1)

    def takeoff(self, altitude=None):
        """이륙 - 목표 고도 도달 시 완료 판정

        [최적화] 독스트링 위치 수정
        기존: self.archived_alt 할당 이후에 독스트링이 위치 → Python이 독스트링으로 인식 못함
        수정: def 바로 아래로 독스트링 이동하여 정상적인 함수 문서화
        """
        if altitude:
            self.set_alt = altitude
        self.archived_alt = self.set_alt * 0.95

        print(f"\n[드론] 이륙 명령 (목표: {self.set_alt}m)...")

        # TAKEOFF 명령
        self.master.mav.command_long_send(
            self.master.target_system,
            self.master.target_component,
            mavutil.mavlink.MAV_CMD_NAV_TAKEOFF,
            0, 0, 0, 0, 0, 0, 0, self.set_alt
        )

        # 이륙 완료 판정
        timeout = 20
        start_time = time.time()

        while time.time() - start_time < timeout:
            msg = self.master.recv_match(type='GLOBAL_POSITION_INT', blocking=True, timeout=0.5)
            if msg:
                current_alt = msg.relative_alt / 1000.0

                print(f"  현재 고도: {current_alt:.2f}m / 목표: {self.set_alt}m", end='\r')

                if current_alt >= self.archived_alt:
                    print(f"\n[드론] 이륙 완료 (고도: {current_alt:.2f}m)")
                    return True

        print(f"\n[드론] 이륙 시간 초과 ({timeout}초)")
        return False

    def set_command(self, cmd):
        if not self.master:
            print("[드론] FC 연결이 없습니다")
            return False

        if isinstance(cmd, list) and len(cmd) == 4:
            vx = cmd[0]
            vy = -cmd[1]
            vz = -cmd[2]
            # [최적화] yaw 정규화 간소화
            # 기존: if yaw_deg > 180: yaw_deg = yaw_deg - 360 (0~360 범위만 처리)
            # 수정: 모듈로 연산으로 임의의 각도를 -180~180 범위로 정규화
            yaw_deg = ((cmd[3] + 180) % 360) - 180
            rotation = math.radians(yaw_deg)
        else:
            raise ValueError("Command must be a list with 4 elements")

        try:
            self.master.mav.set_position_target_local_ned_send(
                0,
                self.master.target_system,
                self.master.target_component,
                mavutil.mavlink.MAV_FRAME_LOCAL_NED,
                0b0000101111000111,
                0, 0, 0,
                vx, vy, vz,
                0, 0, 0,
                rotation, 0
            )
            return True
        except Exception as e:
            print(f"[드론] 명령 전송 실패: {e}")
            return False

    def read_altitude(self):
        """현재 상대 고도를 읽어서 반환"""
        msg = self.master.recv_match(type='GLOBAL_POSITION_INT', blocking=True, timeout=1)
        if msg:
            altitude = msg.relative_alt / 1000.0
            print(f"[드론] 현재 고도: {altitude:.2f}m")
            return altitude
        else:
            print("[드론] 고도 읽기 실패")
            return None
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

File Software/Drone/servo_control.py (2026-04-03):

# servo_control.py
import Jetson.GPIO as GPIO
import time

class Servo:
    def __init__(self, servo_pin=33):
        """
        서보 모터 제어 클래스
        :param servo_pin: GPIO 핀 번호 (기본값: 33)
        """
        self.servo_pin = servo_pin
        self.angle = 0

        # GPIO 설정
        GPIO.setmode(GPIO.BOARD)
        GPIO.setup(self.servo_pin, GPIO.OUT)

        # PWM 설정 (50Hz)
        self.pwm = GPIO.PWM(self.servo_pin, 50)
        self.pwm.start(0)

        # 초기 위치 설정 (0도 - 재장전)
        self.set_angle(0)
        print("[서보] 초기화 완료 (0도 - 재장전 위치)")

    def set_angle(self, angle):
        """
        서보를 지정된 각도로 회전
        :param angle: 목표 각도 (0~180도)

        [최적화] PWM 신호 정지 추가 (서보 지터 방지)
        기존: duty cycle을 설정한 후 계속 유지 → 서보가 미세하게 떨림(지터)
              이는 PWM 신호의 타이밍 지터가 서보 위치 오차로 전달되기 때문
        수정: 목표 각도 도달 후 duty=0으로 설정하여 PWM 신호 정지
              서보는 마지막 위치를 기계적으로 유지하므로 안전함
        """
        if angle < 0:
            angle = 0
        elif angle > 180:
            angle = 180

        # duty cycle 계산 (2.5 ~ 12.5)
        duty = angle / 18 + 2.5
        self.pwm.ChangeDutyCycle(duty)
        time.sleep(0.5)
        # [최적화] PWM 신호 정지 — 서보 지터 방지
        self.pwm.ChangeDutyCycle(0)
        self.angle = angle

        # 각도별 상태 출력
        if angle == 0:
            print("[서보] 0도 - 재장전(idle)")
        elif angle == 180:
            print("[서보] 180도 - 투하")
        else:
            print(f"[서보] {angle}도로 회전")

    def drop(self):
        """소화볼 투하 (180도)"""
        print("[서보] 소화볼 투하")
        self.set_angle(180)

    def reload(self):
        """재장전 위치 (0도)"""
        print("[서보] 재장전")
        self.set_angle(0)

    def cleanup(self):
        """GPIO 정리"""
        try:
            self.pwm.stop()
            GPIO.cleanup()
            print("[서보] GPIO 정리 완료")
        except RuntimeError as e:
            if "Not running on a RPi" not in str(e):
                print(f"[서보] GPIO 정리 중 오류 (무시 가능): {e}")

    def __del__(self):
        """소멸자 - 객체 삭제 시 GPIO 정리"""
        try:
            self.cleanup()
        except Exception:
            pass

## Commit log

2025-05-08 정기 회의록 demo
    회의록 초안 작성
2025-05-08 README.md 업데이트
2025-05-09 Create 2025.05.09(금)
2025-05-09 Update and rename 2025.05.09(금) to 2025.05.09(금).md
2025-05-15 IMX219 젯슨나노 160도 광각 모듈 8MP
2025-05-15 라즈베리파이 카메라모듈 V2, 8MP
2025-05-15 미코에어 405v2 픽스호크 비행 컨트롤러 + 50A 4in1 ESC 스택 콤보
2025-05-15 미코에어 H743 V2 신형 픽스호크 비행 컨트롤러 + 55A 4in1 AM32 ESC 스택 콤보
2025-05-16 라즈베리파이 적외선 카메라모듈 V2, 8MP
2025-05-17 3주차까지 해올 과제 포함
2025-05-19 FC.md 만들기
2025-07-23 Create landing_logic.py
    드론 착륙 로직 코드
    현재 노트북 웹캠으로 구현했으므로 카메라 모듈 연결 후 변환 필요
    카메라 화면 1차 9분할 -> (1 2 3 / 4 5 6 / 7 8 9) 형태
    5번 카메라 화면 2차 9분할 -> (내부 1 2 3 / 내부 4 5 6 / 내부 7 8 9) 형태
2025-07-23 landing_logic.py
    카메라 화면 1차 분할 -> (1 2 3 / 4 5 6 / 7 8 9) 형태
    5번 카메라 화면 2차 분할 -> (내부 1 2 3 / 내부 4 5 6 / 내부 7 8 9) 형태
    현재 노트북 웹캠 기준으로 작성되어 있음
    -> 추후에 카메라 모듈로 코드 수정 필요
    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
2025-07-23 Add files via upload
    화제탐지후 화제 근처로 가는 알고리즘
2025-07-24 Add files via upload
    객체탐지 언더카메라
2025-07-30 Update and rename CSI_Camera to Object_Data_CSI
    객체 탐지
2025-07-30 Create landing_CSI
    착륙
2025-07-30 Update and rename Software/JetsonOrinNanoSuper/Object_Data.py to Software/JetsonOrinNanoSuper/test/Object_Data.py
2025-07-30 Update landing_CSI
2025-08-01 Create 2025.07.1617(수,목)
2025-08-06 MG995기준 서보모터 제어 클레스
2025-08-06 Create throw.py
    1. GPS 좌표로 투척 거리와 고도 차 계산
    2. 45° 각도 기준으로 초기 속도 계산
    3. Jetson.GPIO를 사용해 서보 모터 핀 초기화
    4. 뚜껑 90° 열기 → 일정 시간 유지 → 0°로 닫기
2025-08-06 Create UART1
2025-08-06 Update UART1
2025-08-06 Update main_frame.py
    필요한 동작 대부분 포함됨
    세부 모듈로 재정리 필요
2025-08-07 Update and rename 2025.08.0607().md to 2025.08.0607(수,목).md
2025-08-07 Create UART_MAVLink2_moter
2025-08-07 Create UART_MAVLink2_115200
2025-08-13 Update and rename Software/JetsonOrinNanoSuper/nano/fire_test.py to Software/JetsonOrinNanoSuper/nano/test/fire_test.py
2025-08-14 Update and rename simple_updown.py to 사용방법
2025-08-20 Create uart_communication
2025-08-22 Update and rename Software/JetsonOrinNanoSuper/nano/main.py to Software/drone/main.py
2025-08-22 Update and rename Software/JetsonOrinNanoSuper/nano/DroneCommunicator.py to Software/drone/DroneCommunicator.py
2025-08-22 Update and rename Software/JetsonOrinNanoSuper/nano/pc_server.py to Software/PC/pc_server.py
2025-08-23 Update Fire_detector.py
    중앙정렬 로직 수정해야함
    [Fire_detector.py]
2025-08-27 hover_safe.py 만들기
2025-08-27 pymavlink 라이브러리 상세 만들기
2025-08-27 nonarm_alt_print.py 만들기
2025-08-27 hover_safe.py 업데이트
2025-08-27 drone_controller.py 업데이트
2025-08-27 manual 만들기
2025-09-14 Update JetsonNano Camera Module.md
2025-09-14 Rename JetsonNano Camera Module.md to IMX219 Camera Module.md
2025-09-15 Create IMX477 Camera Module
2025-09-15 Rename IMX477 Camera Module to IMX477 Camera Module.md
2025-09-15 Create 2025.08.2021(수, 목).md
2025-09-15 Create 2025.09.11(목)
2025-09-15 Rename Motor.md to Motor & Propeller.md
2026-04-03 레거시 코드 정리 및 전체 모듈 최적화
    - Legarcy_Data/ 전체 삭제 (테스트/초안/중복 코드 40개+ 파일)
    - Station 카메라 테스트 파일 삭제
    - README.md 전면 재작성 (시스템 아키텍처, 모듈 상세, 통신 프로토콜)
    - pc_server.py: update_gui_with_report 중복 정의 버그 수정
    - Fire_extinguishing.py: goto_gps 루프 밖 1회 호출 버그 수정
    - pc_rpi_server.py: _running 속성 미초기화 버그 수정
    - drone_controller.py: goto_home 무한루프에 60초 타임아웃 추가
    - patrol.py/Fire_extinguishing.py: 이동 루프 타임아웃 추가
    - Landing.py: read_altitude 호출 주기 분리 (1Hz→20Hz 제어루프 복원)
    - servo_co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
    [DroneCommunicator.py, Fire_detector.py, Fire_extinguishing.py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]
2026-04-30 repo: 카테고리별 폴더 정리 및 문서 보강
    - STL/ 하위로 Drone/Station 분리 및 파일명 정리
    - Software/Station_미완성_중단 → Software/Station_WIP
    - README 보강 (배지/TOC, 폴더 구조 갱신)
    - Software/, STL/ 하위 README 추가
    - .gitignore, .gitattributes(LF 정규화), LICENSE(MIT) 추가
    [Drone_4inch_Ball.stl, Drone_BAT_House_Hook.stl, Drone_BAT_House_Lower.stl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]
